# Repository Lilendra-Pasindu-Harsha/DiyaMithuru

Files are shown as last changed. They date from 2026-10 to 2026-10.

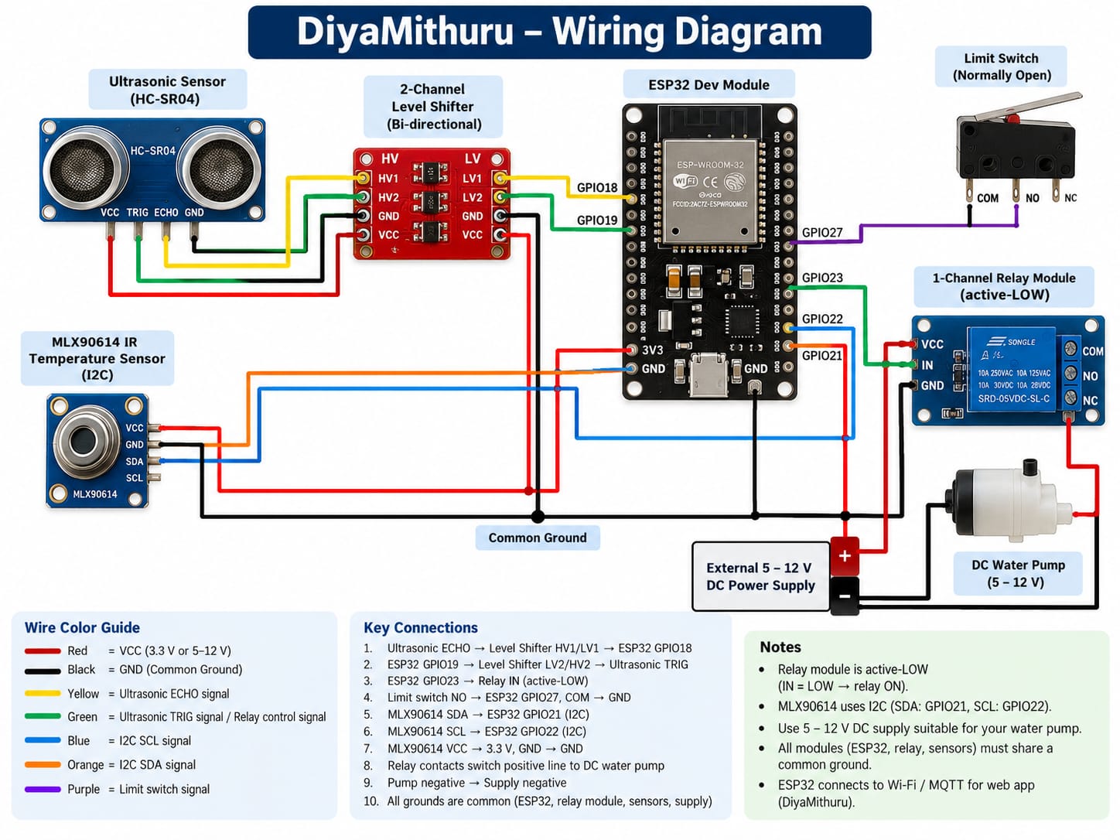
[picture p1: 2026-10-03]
firmware/Wiring Diagram.jpg

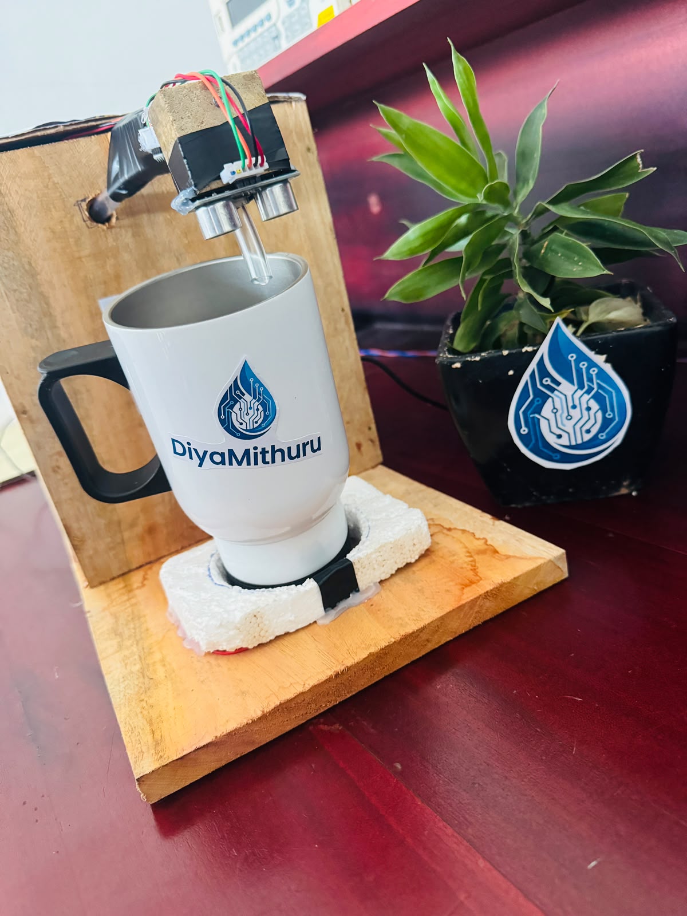
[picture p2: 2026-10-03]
Images/ProtoType/Front View 2.jpg

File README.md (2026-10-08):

# 💧 DiyaMithuru – Smart Liquid Filling Assistant

> **Technology with Compassion. For a More Inclusive Tomorrow.**

DiyaMithuru is an **ESP32-based smart liquid filling assistant** developed as part of the **Engineering Product Design module at General Sir John Kotelawala Defence University , Sri Lanka**.

The system is designed primarily for **visually impaired users**, with the goal of making everyday liquid filling safer, easier, and more independent.

Developed by:

- **Pasindu**
- **Dinuth**

---
Do you want watch all click  https://drive.google.com/drive/folders/1cJ1TSZ0RsK_wuHSQsSrhiei4Du43ArKO?usp=drive_link 

## 🌟 Project Overview

For many people, filling a cup is a simple daily activity. However, visually impaired users, elderly users, and people who require daily assistance may face challenges such as:

- Difficulty identifying the liquid level
- Accidental spills
- Unnecessary water wastage
- Safety concerns when handling higher-temperature liquids
- Dependence on another person

DiyaMithuru addresses these challenges through an embedded automatic filling system with liquid-level monitoring, temperature sensing, remote status monitoring, and user control.

---

## ✨ Key Features

- Automatic cup detection
- Automatic liquid filling
- Automatic refill when the liquid level becomes low
- Pump stops when the cup reaches the full threshold
- Pump stops immediately when the cup is removed
- Liquid-level monitoring using an ultrasonic sensor
- Temperature monitoring using the **MLX90614 IR temperature sensor**
- Manual **ON / STOP / FILL / TEMP** commands
- Wi-Fi setup using **WiFiManager**
- MQTT communication using **HiveMQ Cloud**
- Live device status on the web application
- Spoken announcements through the user interface
- Pump safety timeout
- Sensor fault handling
- Wi-Fi credential reset function

---

## ⚙️ How the System Works

```text
Place Cup
   ↓
Limit Switch Detects Cup
   ↓
Ultrasonic Sensor Measures Liquid Level
   ↓
ESP32 Processes Sensor Data
   ↓
Pump Starts
   ↓
Cup Fills
   ↓
Full Threshold Reached
   ↓
Pump Stops
   ↓
Wait 2 Seconds
   ↓
MLX90614 Measures Drink Temperature
   ↓
Status Published Through MQTT

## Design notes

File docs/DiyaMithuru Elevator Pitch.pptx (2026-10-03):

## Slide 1

DiyaMithuru prototype

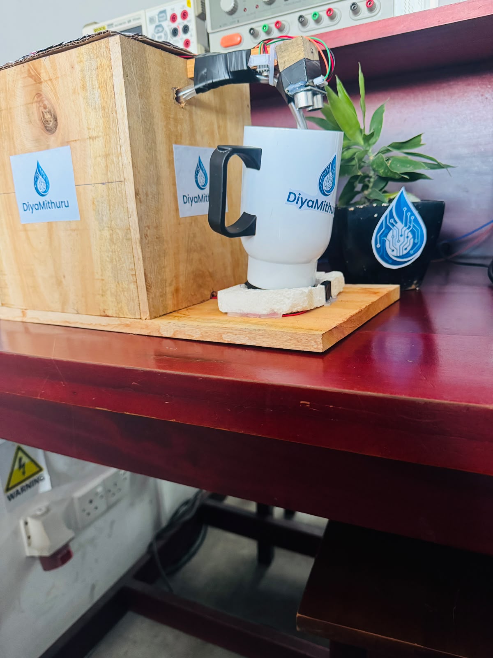
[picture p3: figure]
WhatsApp Image 2026-09-30 at 15.35.14

DiyaMithuru

Smart Liquid Filling Assistant

Technology with Compassion

“A safer, easier and more independent way to fill your cup.”
D/ENG/24/0095/ET
M/ENG/24/001/ET

Designed & Developed in Sri Lanka

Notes: Good evening all .Today we are here to present our newly product DiyaMithuru.It is Smart Liquid Filling Assistant.It helps people fill a cup safely and independently.

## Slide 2

A Simple Task Can Be Difficult

“Filling a cup is not easy for everyone.”

Difficulty identifying liquid level

Risk of spills

WHO IS AFFECTED

Visually Impaired Individuals

Elderly People

People needing daily assistance

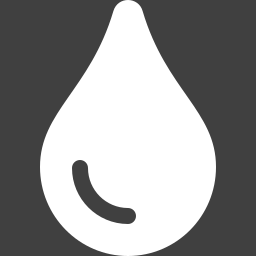
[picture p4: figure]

Safety concerns

Dependence on others

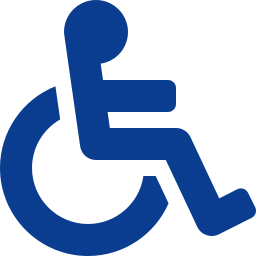
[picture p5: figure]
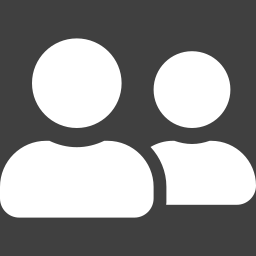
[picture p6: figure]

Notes: Many people find it difficult to fill a cup. Visually impaired and elderly people may spill hot liquids or need help from others.

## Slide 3

Meet DiyaMithuru

Smart Assistance for Everyday Liquid Filling

WhatsApp Image 2026-09-30 at 15.35.13

Automatic Filling

Temperature Monitoring

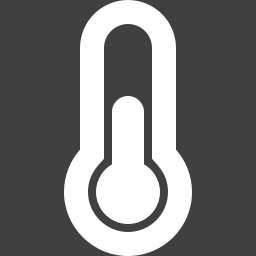
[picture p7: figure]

Audio Indication

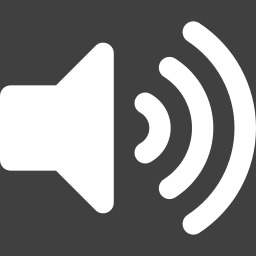
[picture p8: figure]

Inclusive Design

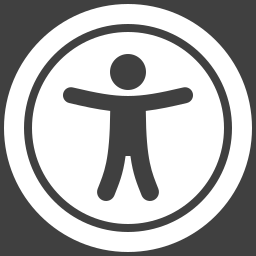
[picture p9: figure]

“Designed to make everyday liquid filling safer, simpler and more independent.”

PLACE

→

DETECT

→

FILL

→

INDICATE

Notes: DiyaMithuru detects the cup, fills it automatically, checks the temperature, and gives an audio indication. It makes filling safer and easier.

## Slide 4

Designed for Real Daily Needs

PRIMARY USER

Visually Impaired Individuals

SECONDARY USERS

Elderly People

Children & Caregivers

Recovery / Patient Support

General Home Users

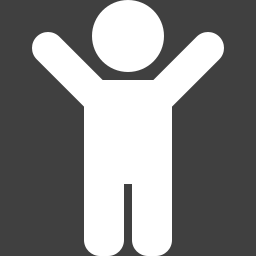
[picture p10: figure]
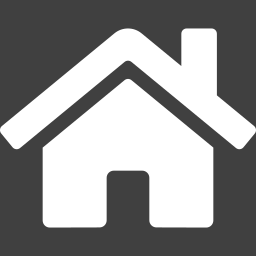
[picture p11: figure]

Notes: It is mainly designed for visually impaired people. It can also help elderly people, caregivers, patients, and families.

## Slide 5

How DiyaMithuru Works

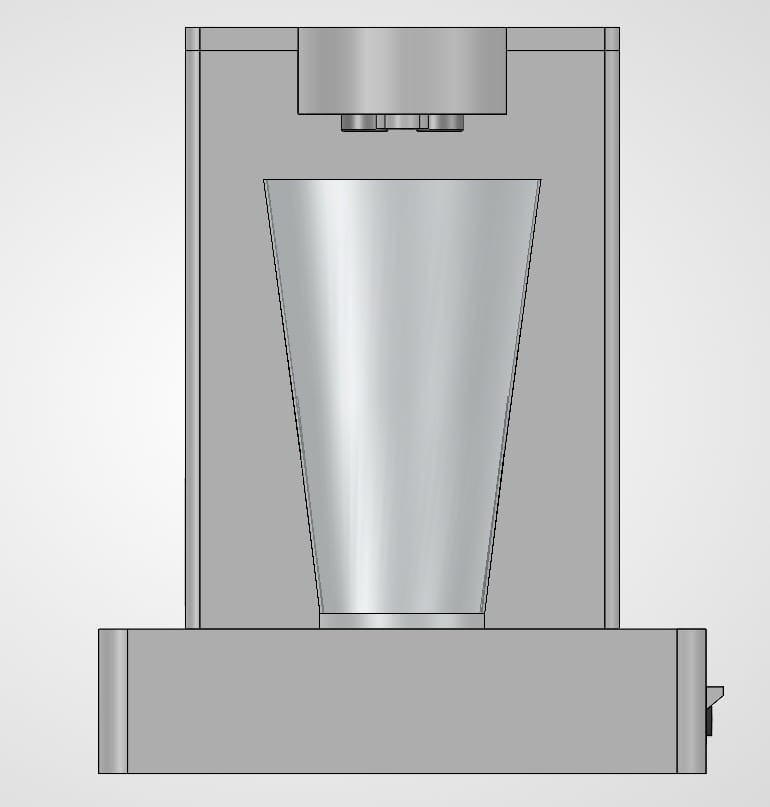
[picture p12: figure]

ESP32 Controller

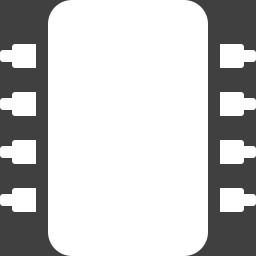
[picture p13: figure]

Ultrasonic Sensor

Temperature Sensor

Relay Module

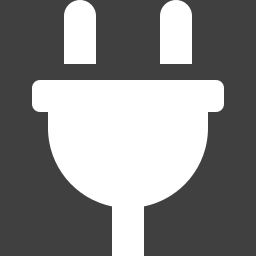
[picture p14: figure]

DC Water Pump

12 V Power Supply

1

Place the cup

›

2

Cup is detected

›

3

ESP32 processes the input

›

4

Pump dispenses the liquid

›

5

Temperature is monitored

›

6

Audio indication informs the user

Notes: The user places a cup. The system detects it, fills the liquid, monitors the temperature, and gives an audio notification when finished.

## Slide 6

More Than Just a Product

GREATER INDEPENDENCE

IMPROVED SAFETY

MORE CONFIDENCE

EASIER DAILY LIVING

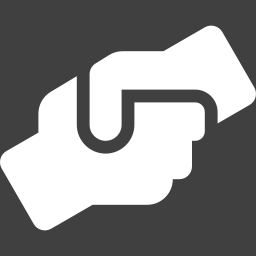
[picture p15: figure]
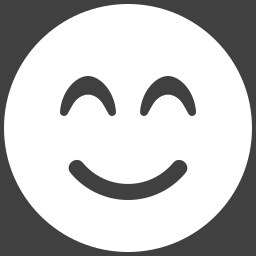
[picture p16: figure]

Supporting Inclusive Technology in Sri Lanka

Technology with Compassion.

Visually impaired user

Elderly user

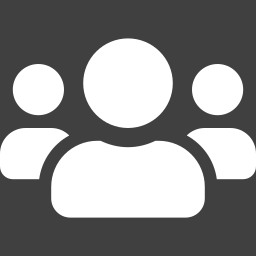
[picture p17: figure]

Family / caregiver

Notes: IMPACT - 20s. Independence, safety, confidence, easier daily living. Close on Technology with Compassion.

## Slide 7

From User Need to Real Product

User Feedback

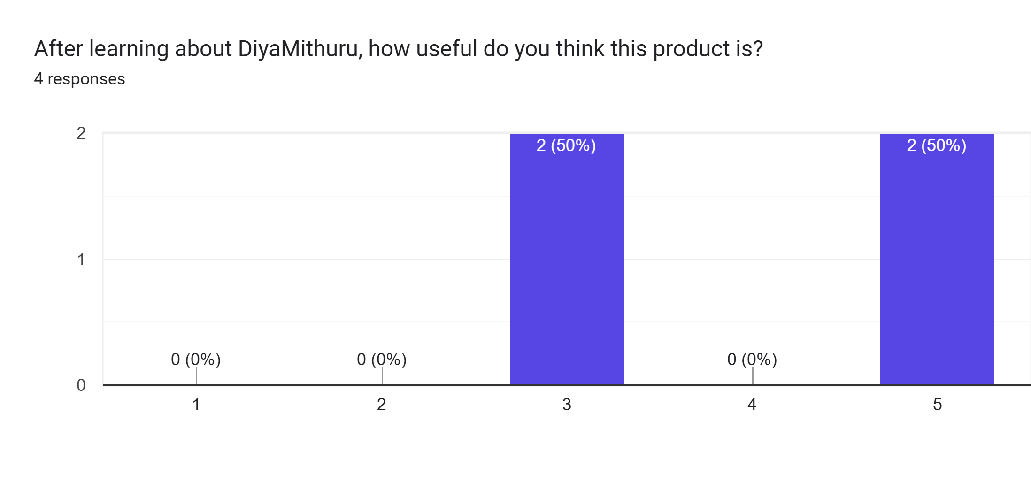
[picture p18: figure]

[INSERT REAL CUSTOMER FEEDBACK]

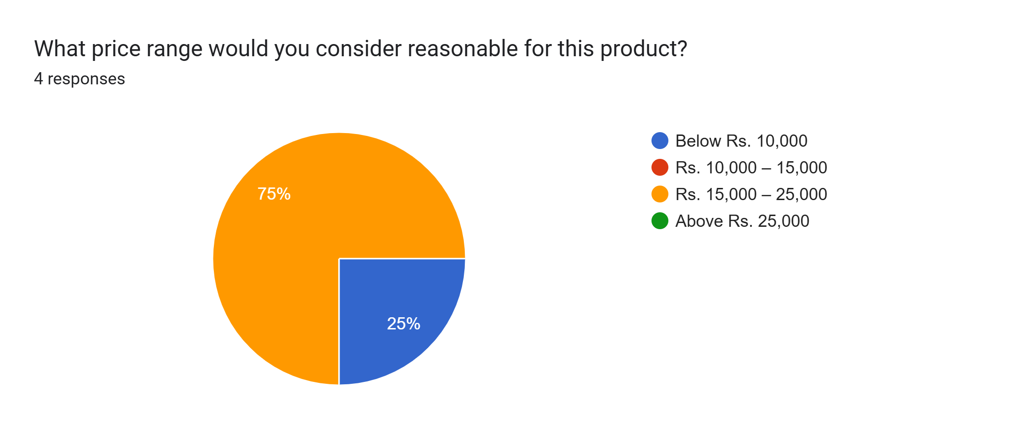
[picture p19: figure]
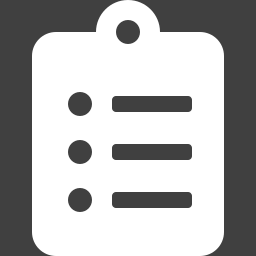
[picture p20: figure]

Google Form Survey

Prototype Testing

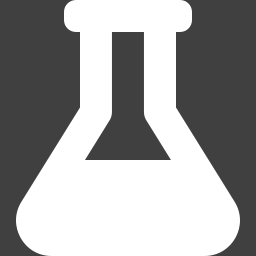
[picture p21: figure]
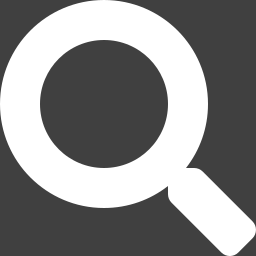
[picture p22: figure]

Customer Requirement Analysis

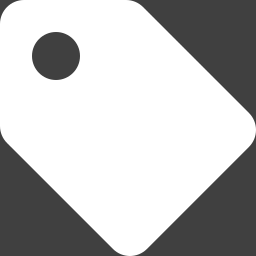
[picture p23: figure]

Price Validation

PRODUCT-MARKET FIT

LOCALLY DEVELOPED

AFFORDABLE

USER-CENTERED

INCLUSIVE

SIMPLE TO USE

Link - https://docs.google.com/forms/d/1FdYKrwL7_DrpVTMPInImFrXas6RZh5WQtF1M-O45piI/edit (https://docs.google.com/forms/d/1FdYKrwL7_DrpVTMPInImFrXas6RZh5WQtF1M-O45piI/edit)

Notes: We collected user feedback, tested the prototype, and analyzed customer needs. The results show that DiyaMithuru is useful and affordable.

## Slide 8

Affordable Assistive Technology

STANDARD PRICE

~~LKR 15,000~~

PROMOTIONAL OFFER: 5% DISCOUNT

PROMOTIONAL PRICE

LKR 14,250

INSTALLMENT PLAN

LKR 5,000 / month

for 3 months · 0% Interest

SCAN

1-Year Hardware Warranty

Free Islandwide Delivery

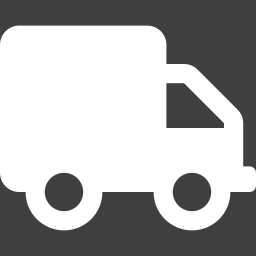
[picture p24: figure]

Personal Onboarding

Wall Power Adapter & Accessories

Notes: The price is LKR 15,000, with a promotional price of LKR 14,250. We also offer installments, a warranty, and free delivery.

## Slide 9

FUTURE DEVELOPMENT

Smart Connectivity
Using AI

IoT Integration using Camera

Improved Audio Guidance
in Tri Basha

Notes: FUTURE - 5s. Roadmap only. Future development items are not current features.

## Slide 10

Thank You !

Technology with Compassion

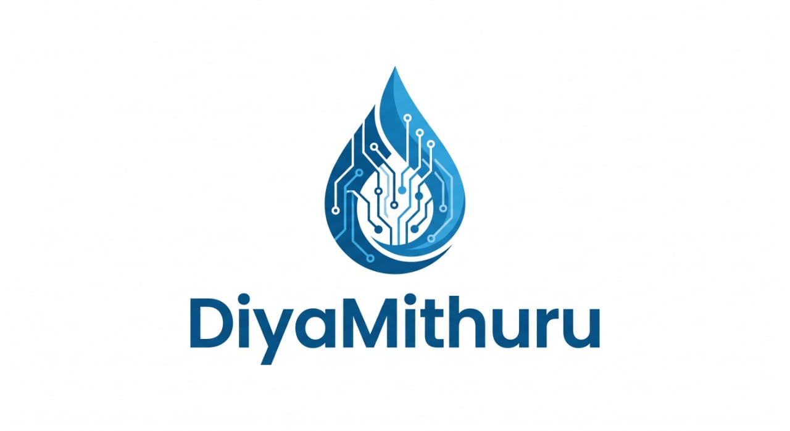
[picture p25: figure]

Scan to know more

“For a More Inclusive Tomorrow”

Designed & Developed in Sri Lanka

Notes: Thank you for listening. DiyaMithuru is Technology with Compassion, created for a more inclusive tomorrow.

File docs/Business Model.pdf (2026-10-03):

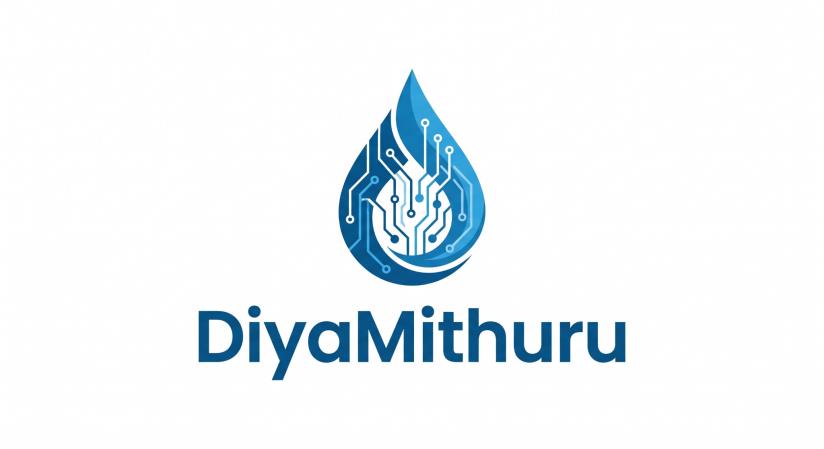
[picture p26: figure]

# BUSINESS MODEL, PRODUCT COST

# & SWOT ANALYSIS


## SMART LIQUID FILLING ASSISTANT

DiyaMithuru is an inclusive smart liquid filling assistant designed to make routine liquid dispensing safer and easier. The primary design focus is visually impaired users, while the commercial concept also considers older adults, caregivers, children/baby-care routines, and people who need support with regular hydration.

The proposed business approach is a direct-to-customer model supported by institutional partnerships, a simple web-based pre-order channel, an upfront payment option, and a 0% three-month installment plan. The standard selling price is LKR 15,000, with a limited promotional cash price of LKR 14,250.

### 1. BUSINESS MODEL

The business model converts the engineering prototype into a practical customer offering. It focuses on affordability, accessibility, local support, and a clear route from prototype validation to small-batch sales.

Customer Segments Primary: visually impaired individuals. Secondary: older adults, caregivers, families, rehabilitation users and people who need assisted hydration. Institutional: hospitals, elder-care facilities, rehabilitation centres, NGOs and accessibility programmes. | Value Proposition A simple smart filling assistant that reduces manual pouring, supports safer liquid handling, improves independence and provides an accessible home-use experience at a locally targeted price.
Channels Direct website/pre-order page, social media promotion, university exhibitions, demonstrations, healthcare/rehabilitation partnerships, NGOs and direct institutional sales. | Customer Relationships Product demonstration, personal onboarding, one-year hardware warranty, user guidance, after-sales support and feedback collection for future product improvement.
Revenue Streams Standard outright sale: LKR 15,000. Promotional full-payment price: LKR 14,250 (5% discount). 0% installment plan: LKR 5,000 per month for 3 months. Future revenue may include institutional/bulk sales and upgraded product versions. | Key Activities Prototype refinement, assembly, quality checking, user testing, supplier sourcing, marketing, order fulfilment, customer onboarding, warranty support and continuous design improvement.
Key Resources ESP32-based control system, sensors and pump assembly, product enclosure, design files, website/pre-order channel, engineering know-how, user feedback and supplier network. | Key Partners Electronics suppliers, fabrication/enclosure providers, healthcare/rehabilitation organisations, disability-support organisations, delivery partners and academic/technical mentors.
Cost Structure Electronic components, enclosure/fabrication, pump and tubing, power adapter, assembly/testing labour, packaging, delivery, warranty reserve, marketing and website/administration costs. | Growth Path Start with small-batch direct sales, validate reliability and user satisfaction, build institutional partnerships, improve manufacturability, then expand to wider assistive/home-care markets.

Business model statement: DiyaMithuru will initially follow a direct-to-customer, small-batch model to keep the product affordable and maintain close contact with users. Institutional partnerships can later support bulk deployment and broader market reach.

1.1 Proposed Sales and Payment Model

Option | Customer Payment | Total Revenue | Purpose
Standard full payment | LKR 15,000 once | LKR 15,000 | Normal retail sale
Promotional full payment | LKR 14,250 once | LKR 14,250 | 5% launch promotion
0% installment plan | LKR 5,000 x 3 months | LKR 15,000 | Improves affordability / access

### 2. PRODUCT COST AND PRICING

The following cost model is an estimated planning budget for one DiyaMithuru unit. It is intended for the assignment business case and should be updated using actual purchase receipts, supplier quotations and fabrication costs before the final presentation.

Item | Qty | Estimated Unit Cost
(LKR) | Estimated Total (LKR)
ESP32 controller | 1 | 1,600 | 1,600
Ultrasonic cup-detection sensor | 1 | 450 | 450
Temperature sensor | 1 | 500 | 500
1-channel relay module | 1 | 250 | 250
Logic-level shifter | 1 | 300 | 300
DC liquid pump | 1 | 1,200 | 1,200

Wall power adapter /
power unit | 1 | 1,000 | 1,000

Tubing and fluid
connectors
1 | 400 | 400

Product enclosure /
fabricated body | 1 | 1,700 | 1,700

Wiring,
PCB/prototyping board,
fasteners
1 | 600 | 600

Audio indication
hardware | 1 | 450 | 450

Packaging, user guide
and warranty materials | 1 | 350 | 350

Assembly and functional
testing allowance | 1 | 700 | 700

Estimated
manufacturing cost per
unit

LKR 9,500

2.1 Pricing and Margin

Scenario | Selling Price | Gross Profit / Unit | Gross Margin
Standard retail | LKR 15,000 | LKR 5,500 | 36.7%
5% promotional full payment | LKR 14,250 | LKR 4,750 | 33.3%

Installment (3 x LKR
5,000) | LKR 15,000 | LKR 5,500 | 36.7%

Gross margin is before delivery, warranty claims, marketing, payment collection costs, taxes/fees and other overheads. These should be tracked separately during commercialization.

2.2 Small-Batch Financial Projection

Scenario | 20-Unit Revenue | 20-Unit Product
| | Cost | Gross Contribution
Standard price | LKR 300,000 | LKR 190,000 | LKR 110,000

All units at promo
price | LKR 285,000 | LKR 190,000 | LKR 95,000

Illustrative mixed
sales (10 standard +

### 10 promo)

LKR 292,500 | LKR 190,000 | LKR 102,500

2.3 Financial Plan for the First Product

- Use the website/pre-order QR code and product demonstration to collect the first confirmed order.
- Offer the standard price of LKR 15,000, or a limited 5% promotional full-payment price of LKR 14,250.
- Offer the 0% installment option at LKR 5,000 per month for three months while keeping the total price at LKR 15,000.
- Purchase components against confirmed orders where possible to reduce inventory risk and preserve working capital.
- Record actual component, fabrication, delivery and warranty costs for each unit so the final selling price can be refined using real data.

Estimated first-unit economics at promotional price: Revenue LKR 14,250 - estimated product cost LKR 9,500 = estimated gross contribution LKR 4,750 before delivery, warranty and marketing overheads.

### 3. SWOT ANALYSIS

The SWOT analysis identifies internal product/business factors and external market factors that can affect DiyaMithuru during prototype validation and early commercialization.

STRENGTHS

- Inclusive, user-centered concept with a clear
primary accessibility need.
- Locally developed solution that can be supported and adapted for Sri Lankan users.
- Simple embedded architecture based on commonly available components.
- Automatic cup detection, liquid dispensing, temperature monitoring and audio indication improve ease of use.
- Potential to serve more than one customer segment while retaining a strong accessibility focus.
- Web-based marketing/pre-order channel enables low-cost direct customer reach.

WEAKNESSES

- Alpha-stage product with limited long-term reliability and field testing.
- Current unit cost may be high relative to mass-produced household dispensers.
- Performance depends on correct sensor positioning, calibration and consistent cup placement.
- Small-batch fabrication can cause variation in enclosure quality and assembly time.
- Warranty, delivery and installment commitments can create extra cost and cash-flow pressure.
- Product is not a medical measuring device; claims about patient fluid requirements must remain carefully limited.

OPPORTUNITIES

- Growing interest in inclusive design, independent living and smart-home assistance.
- Partnership opportunities with hospitals, rehabilitation centres, elder-care services and NGOs.
- Potential institutional/bulk orders after successful user validation.
- Future versions can improve portability, manufacturability, connectivity and personalised accessibility features.
- Local manufacturing and assembly may reduce import dependence and improve after-sales support.
- Positive university exhibition and survey feedback can support further product development.

THREATS

- Competition from low-cost water dispensers, smart appliances and imported assistive products.
- Component price changes or shortages can reduce margins.
- Electrical/liquid safety concerns may require stronger testing and compliance before commercial release.
- Customer adoption may be slow without demonstrations and trust-building.
- Sensor or pump failure can directly affect customer confidence in the product.
- Unvalidated marketing claims could create reputational or regulatory risk.

3.1 Actions from the SWOT

Priority | Action

Validate reliability

Run repeat filling tests, temperature-sensor checks and user trials; document failures and improvements.

Control product cost

Use | supplier | quotations, | standardise
components and redesign the enclosure for easier small-batch manufacturing.

Build customer trust

Demonstrate the product, clearly explain limitations, provide onboarding and publish genuine user feedback.

Manage commercial risk

Define warranty terms, installment collection rules, delivery cost policy and a small warranty reserve per unit.

### 4. CONCLUSION

DiyaMithuru has a credible early-stage business pathway because the product addresses an identifiable accessibility need, uses a comparatively simple embedded architecture and can initially be sold through direct customer relationships. The proposed LKR 15,000 standard price and LKR 14,250 promotional price provide a workable starting point under the estimated LKR 9,500 unit-cost model, but the financial case must be updated with real supplier and fabrication data before commercial launch.

The immediate business priority is not large-scale expansion. It is to validate reliability, confirm customer willingness to pay, control unit cost and build trust through real demonstrations and user feedback. These results can then support institutional partnerships and future product development.

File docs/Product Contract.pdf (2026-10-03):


# PRODUCT CONTRACT


# SMART LIQUID FILLING ASSISTANT

Product | DiyaMithuru
Category | Assistive Technology
Prototype | Alpha
Design focus | Inclusive, user-centered operation

### 1. PRODUCT DESCRIPTION

DiyaMithuru is an inclusive smart liquid filling assistant designed to reduce the need for visual judgement and manual pouring. The alpha prototype uses an ESP32-based control system, ultrasonic sensing for cup presence, temperature sensing, relay-controlled pumping and audio

indication using web dashboard. When a cup is correctly positioned, the system can initiate controlled dispensing, monitor the liquid condition, provide visual and non-visual feedback using web site , and stop the pump according to the programmed filling condition. ALPHA SCOPE
Prototype validation is based primarily on water and indoor home-use conditions. It is not a certified medical dosing device and should not be presented

### as one. 2. VALUE PROPOSITION

Who is the user?

Primary: people with full visual impairment who need a non-visual way to fill a cup. Secondary users include older adults, people with reduced dexterity, caregivers, and people recovering from illness who

benefit from easier hydration routines. How does the user benefit?

Less dependence on sight and continuous manual pouring; easier cup placement and filling; audio status feedback; temperature awareness and reduced risk of accidental dispensing when a cup is not correctly positioned. Where and when is it used?

Primarily indoors at home, including kitchens, dining spaces, bedside areas and assisted-living

environments. It can support routine drinking-water and beverage preparation. Why would someone want it?

It combines simple automation and inclusive interaction in one affordable local product, helping turn a common daily task into a more predictable and independent experience.

### 3. PRIMARY USER PERSONA

Persona | Nadeesha - hypothetical primary user
Profile | 32-year-old adult with full visual impairment who wants to prepare drinking water independently at home. Current challenge
| Cannot visually judge cup position or liquid level and may need assistance to avoid spills or unsafe handling. Goals
| Independent operation, minimal controls, clear audio feedback, predictable filling, simple cleaning, and safe use around the home. Critical needs
| Non-visual operation; cup-presence interlock; automatic pump control; temperature awareness;

audible start/complete/warning feedback. 4. TARGET MARKET

Primary market: Individuals and households where a visually impaired person wants greater independence in daily liquid filling. Secondary market: Older adults, people with reduced hand dexterity or mobility, caregivers, and

families supporting children or people in recovery. Institutional market: Rehabilitation centers, elder-care settings, disability-support organizations, selected healthcare environments, NGOs and inclusive-living programs. Positioning: Affordable, locally developed assistive technology focused on simple operation, accessibility, and everyday practicality.

### 5. USER NEEDS, PRODUCT ATTRIBUTES & ENGINEERING SPECIFICATIONS

The following requirements convert user needs into measurable design targets. Numeric values are acceptance targets for the alpha prototype and should be confirmed by testing before final
submission. User Need | Product Attribute | Required Function
Engineering
Specification /
Acceptance Target

Verification

Independent, non- visual use Cup detection

System shall identify a
correctly positioned cup
before enabling liquid
dispensing. | Target: >=95% successful detection in 20 placement
trials. | Repeated placement
test

No accidental
dispensing
Safety interlock | Pump shall remain OFF
when no cup is detected. | Target: 20/20 no-cup trials
with zero unintended
pump activation. | No-cup safety test

Quick operation Control response

System should respond
promptly after valid cup
detection. | Target: pump control response <=1.0 s after
stable valid detection. | Stopwatch

Consistent filling

Automatic
dispensing
Liquid | shall | be
dispensed | using | a
programmed | filling
condition rather than
continuous | manual
control. | Target: | repeated | fill
quantity within +/-10%
under the same cup, pump

and supply conditions. 10-fill volume test

Automatic
completion

Pump control

Pump shall turn OFF
automatically at the
programmed fill
condition and include a
maximum | run-time
safeguard. | Target: automatic stop every cycle; maximum continuous pump ON time
<=60 s. | Cycle test

Temperature
awareness

Temperature
monitoring

System shall measure
liquid temperature over
the normal beverage
range. | Design target: 0-100 degC measurement range; +/-2 degC accuracy from 20-80
degC. | Compare | with
| reference thermometer

User Need | Product Attribute | Required Function

Engineering
Specification /
Acceptance Target

Verification

Clear non-visual
feedback | Audio indication
Provide | audible
indication for key states
such as ready/start, completion | and
warning. | Target: distinct audible cues; minimum 65 dBA at 0.5 m in a quiet indoor
setting. | Sound-level / user recognition test
Simple interaction | User interface

Normal operation shall
not | require | a
touchscreen or visual
menu. | Target: <=1 intentional user action after placing the cup; audio feedback
available. | Task analysis / user trial

Low-voltage home
use

Power & electrical
safety

Use a low-voltage DC
supply for the prototype
electronics and pump
system. | 5-12 V DC system supply; wall adapter used as
external mains interface. Visual inspection / voltage check

Reliable operation System reliability

System shall complete
repeated fill cycles
without controller lock- up or pump-control
failure. | Target: >=100 consecutive
bench cycles without
control failure. | Endurance test
Indoor | liquid
handling

Operating scope

Alpha prototype shall be
validated with water and
similar low-viscosity
test liquids only after
compatibility check. | Minimum | validation
| medium: | water;
electronics protected from
normal splash exposure by
enclosure/layout. | Inspection / functional test

Affordable
ownership

Cost target

Product should remain
accessible relative to
complex | imported
assistive systems. | Planning | target:
| manufacturing | cost
<=LKR 9,500; standard
selling price <=LKR
15,000. | BOM and cost review

### 6. ALPHA PROTOTYPE ACCEPTANCE CRITERIA

The alpha prototype will be considered successful when the core assistive function can be demonstrated safely and repeatedly under the defined test conditions. • Cup presence is detected reliably before dispensing begins. • The pump does not activate when a cup is absent or outside the valid placement zone. • Dispensing starts and stops automatically according to the programmed control logic. • Temperature sensing produces stable readings that are reasonably consistent with a reference

thermometer. • Audio indication communicates key system states without requiring visual feedback. • The device completes repeated demonstrations without leakage reaching exposed electronics

or causing control failure. • The primary user or a suitable representative can understand the operating sequence with

minimal instruction. • The final prototype enclosure and product form present a resolved, natural-product appearance

suitable for exhibition demonstration.

### 7. Verification Plan

Test | Method | Pass Evidence
Cup detection | 20 correct cup placements | Detection success rate and false negatives
No-cup interlock | 20 trials without a cup | Unintended pump activations = 0
Fill repeatability | 10 fills using same cup and setup | Measure each fill volume; calculate variation
Automatic stop | 10 full cycles | Pump stops without manual continuous control
Temperature | Compare at approximately 20, 40, 60 and 80 degC | Error against reference thermometer
Audio indication | Test ready/start/complete/warning cues | Cue is audible and distinguishable at 0.5 m
Endurance | 100 bench cycles | Record control failures, leaks or abnormal operation
User validation | Task trial with target-user representative | Observe independence, errors, ease of use and feedback

### 8.PRODUCT BOUNDARIES & ASSUMPTIONS

- The alpha prototype is intended for indoor demonstration and home-assistance scenarios. • The product is not positioned as a certified medical device, clinical fluid meter, or replacement

for professional medical advice. • For the final engineering report, measured prototype dimensions, weight, actual sensor

accuracy, measured fill repeatability, and endurance results should replace any unverified target values. • Web-based logging, mobile applications, AI recognition and smart-home connectivity are

outside the current alpha-prototype contract unless separately implemented and demonstrated. • Commercial claims such as warranty, delivery, manufacturing cost and retail price are

business-plan assumptions until a real production and service process is established.

Prepared by | Reviewed by | Date

### 9.CONTRACT SIGN-OFF


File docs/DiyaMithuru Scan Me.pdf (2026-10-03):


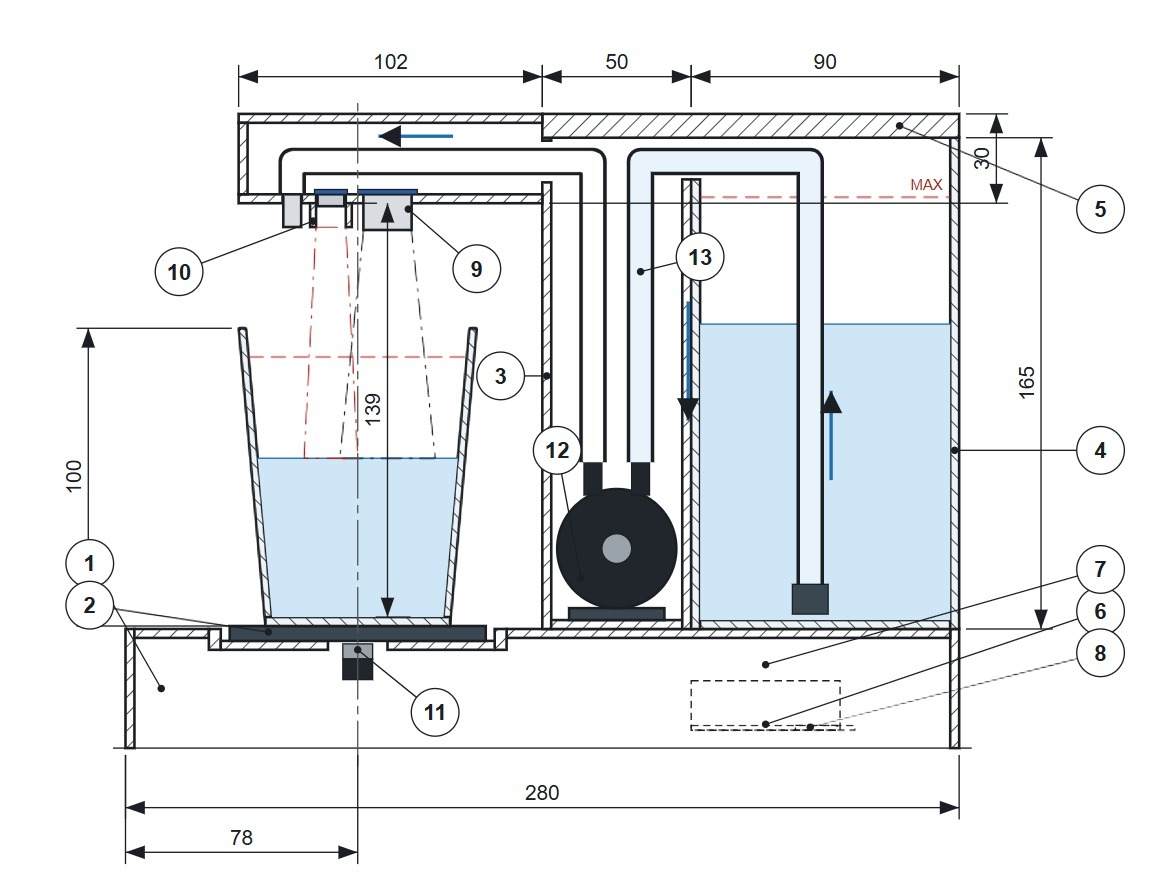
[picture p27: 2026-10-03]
Drawings/Mechanical/Side View with Dimensions.jpeg

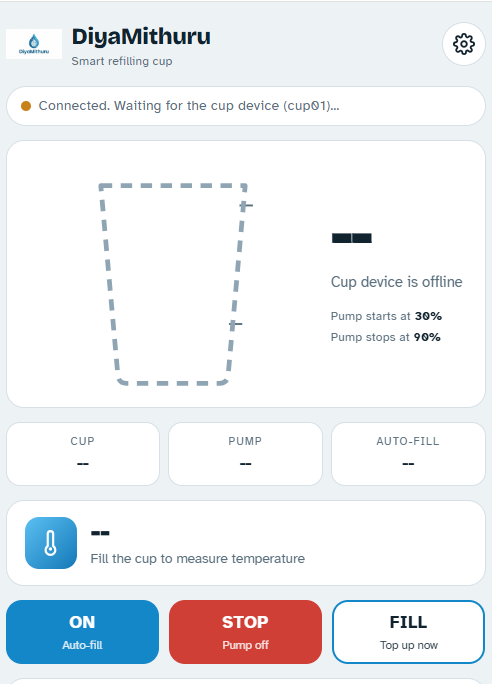
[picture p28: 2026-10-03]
Images/Working Unit Web Site/View 1.png

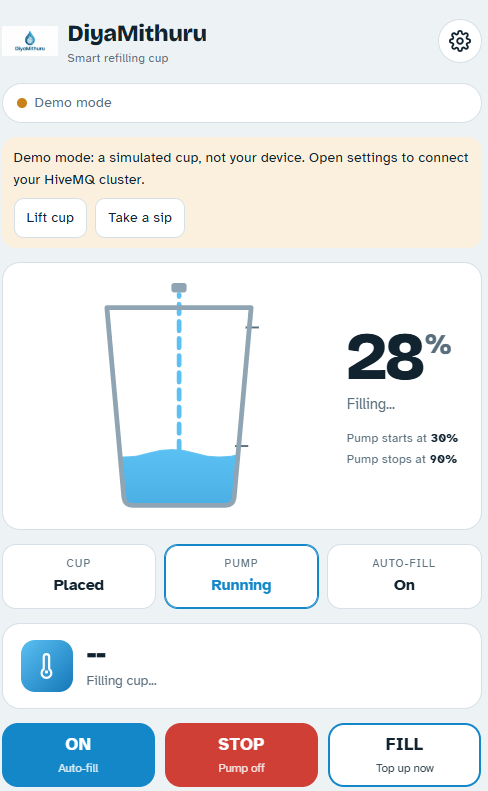
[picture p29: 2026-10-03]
Images/Working Unit Web Site/View 4.png

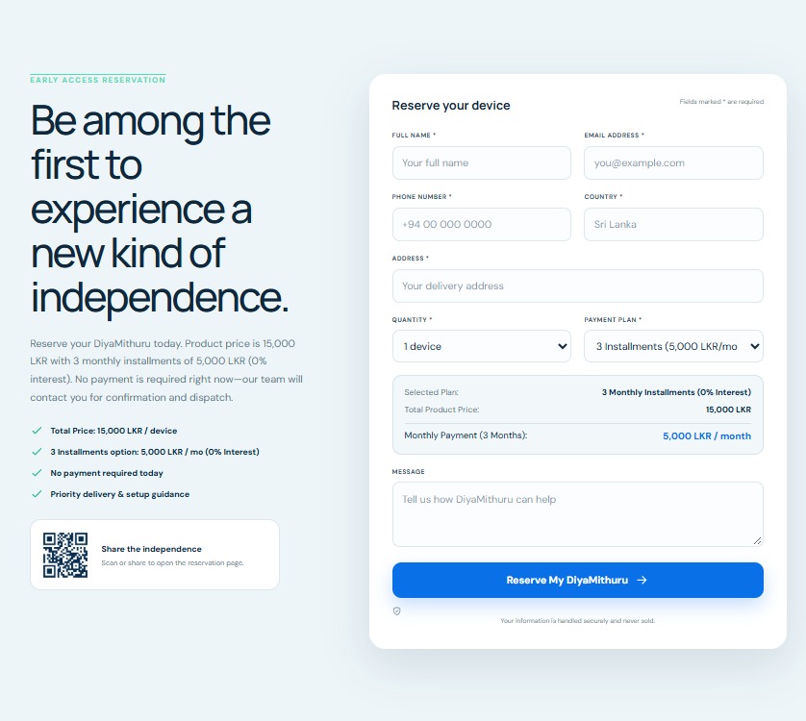
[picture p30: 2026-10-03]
Images/Marketing Web Site/View 8.jpg

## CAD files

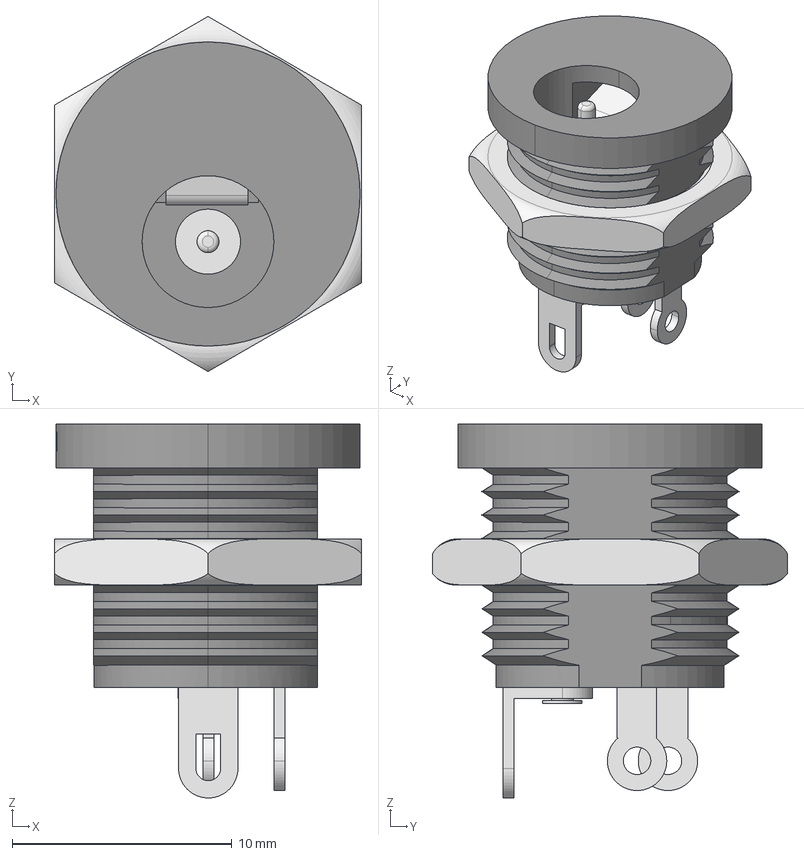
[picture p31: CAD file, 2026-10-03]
Drawings/CAD/Assem1/Socket Panel.stp
14.0 x 16.2 x 17.0 mm
Socket Panel
pin
Nut

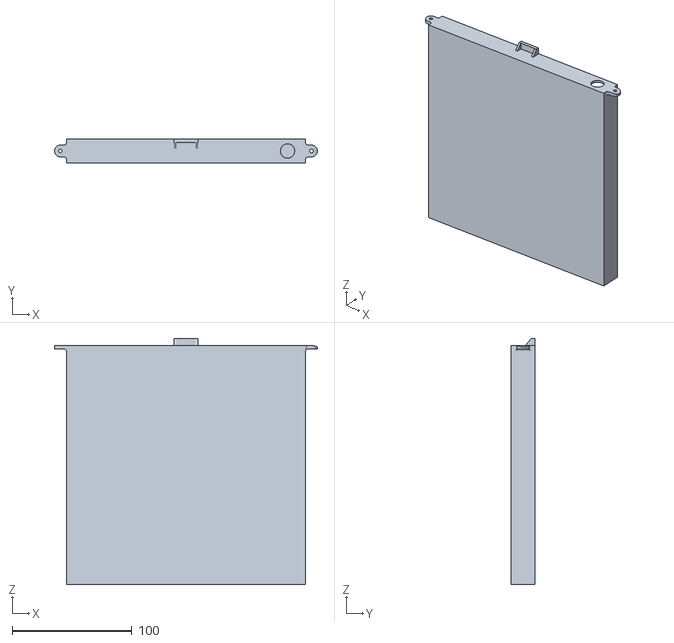
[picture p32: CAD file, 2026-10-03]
Drawings/CAD/pcb plate.STL
219.9 x 20.0 x 206.0

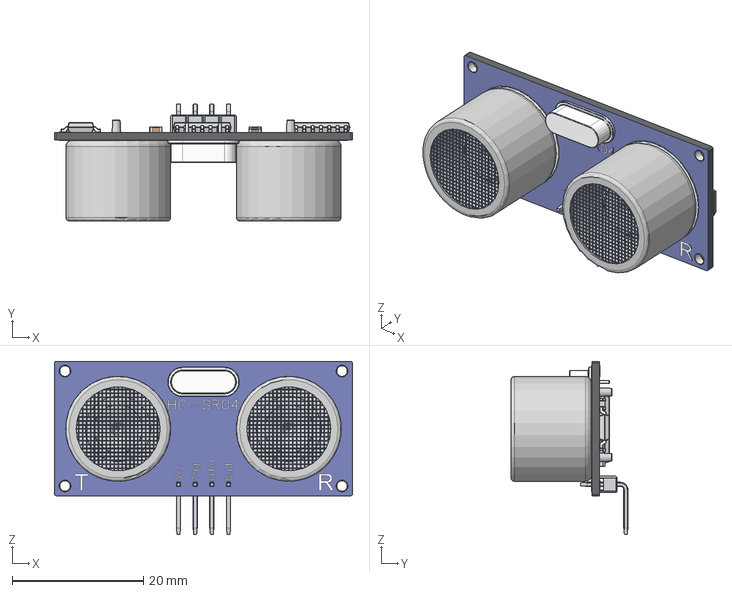
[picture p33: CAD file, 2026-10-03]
Drawings/CAD/Assem1/HC-SR04_UltraSonic Sensor.step
45.4 x 17.8 x 26.4 mm

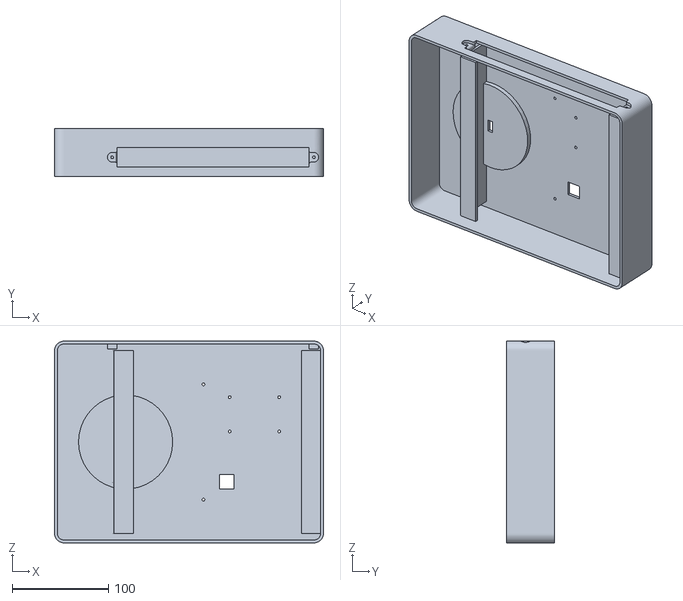
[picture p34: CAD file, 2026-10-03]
Drawings/CAD/base.STL
280.0 x 50.0 x 210.0

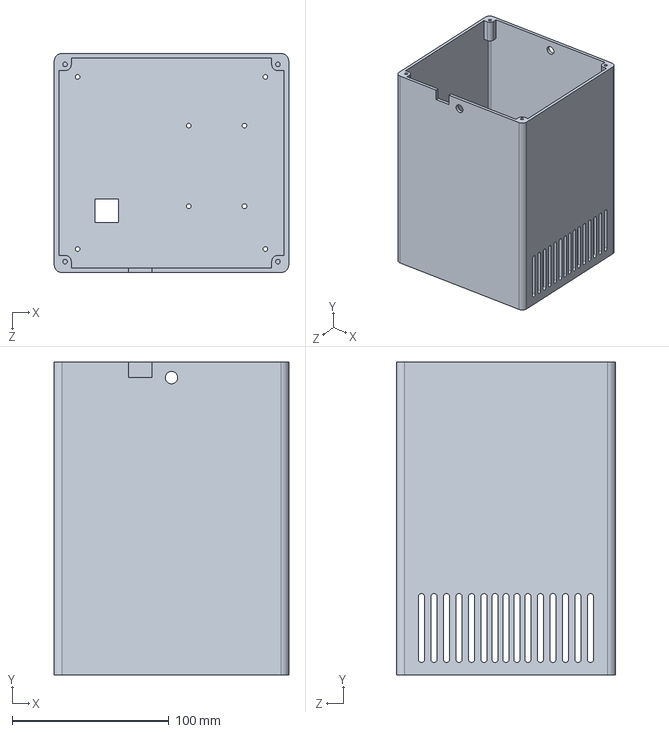
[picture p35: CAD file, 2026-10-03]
Drawings/CAD/Assem1/Drypump_bay.SLDPRT
150.0 x 200.0 x 140.0 mm

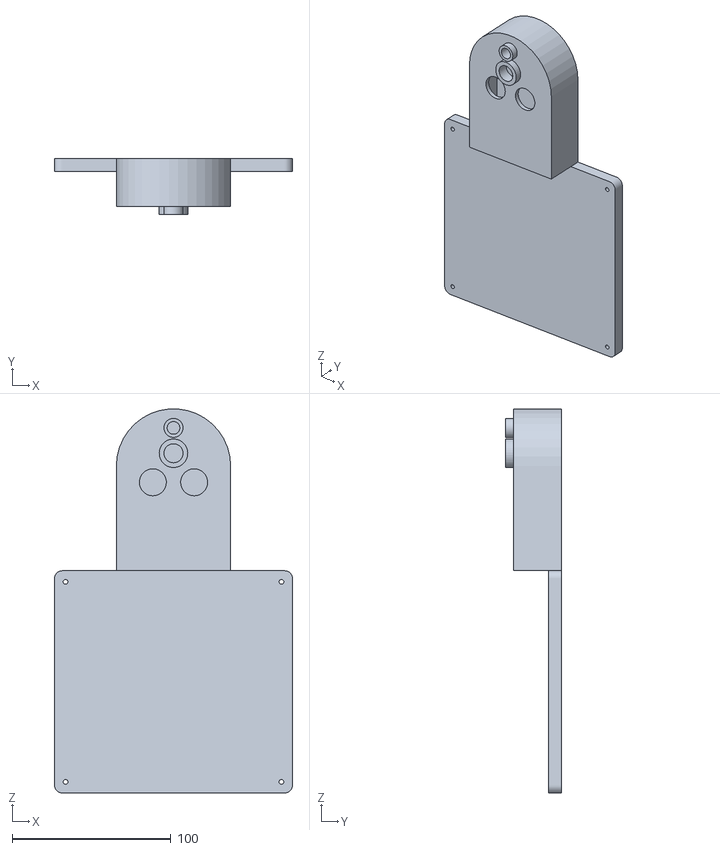
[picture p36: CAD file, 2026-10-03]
Drawings/CAD/Lid + sensor arm.STL
150.0 x 35.0 x 241.9

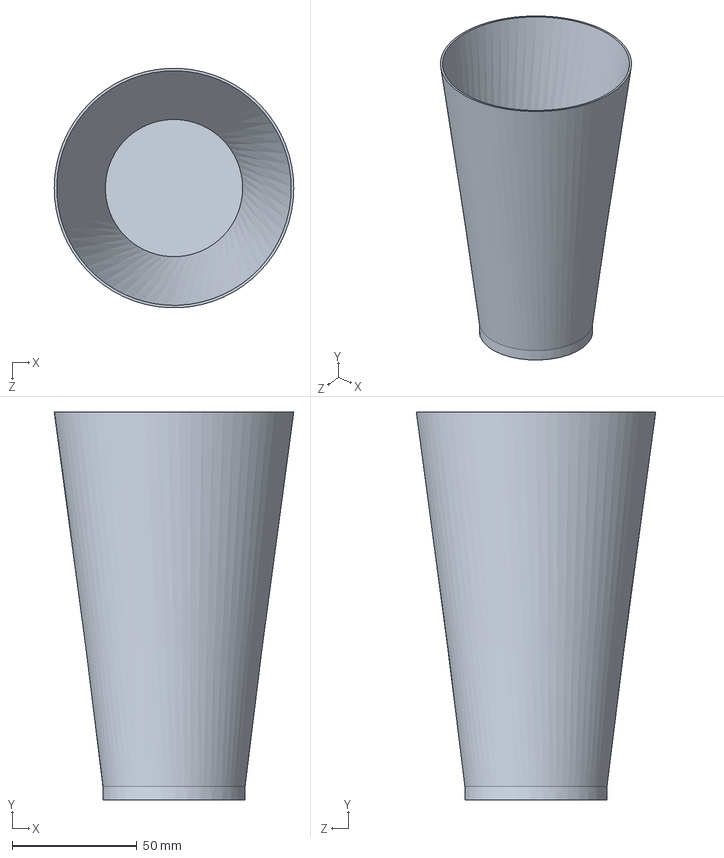
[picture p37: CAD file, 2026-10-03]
Drawings/CAD/Assem1/Water glass.SLDPRT
96.0 x 155.5 x 96.0 mm

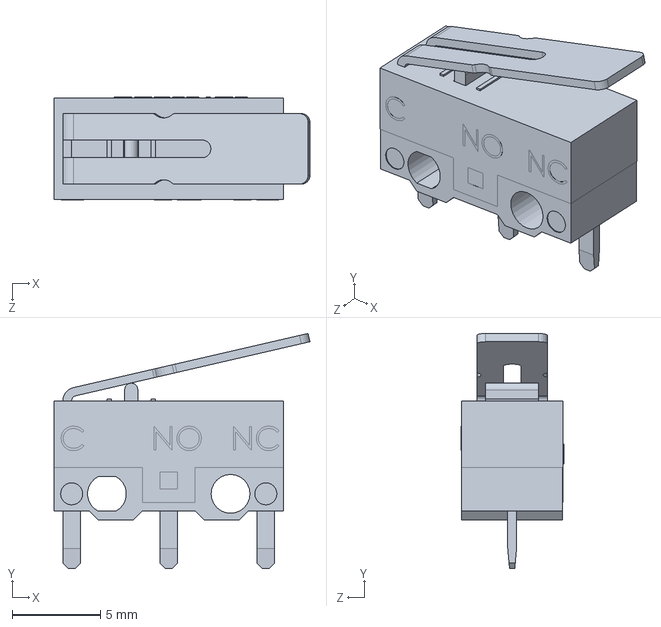
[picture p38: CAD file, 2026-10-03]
Drawings/CAD/Assem1/Limit_Switch.SLDPRT
14.5 x 13.3 x 5.81 mm

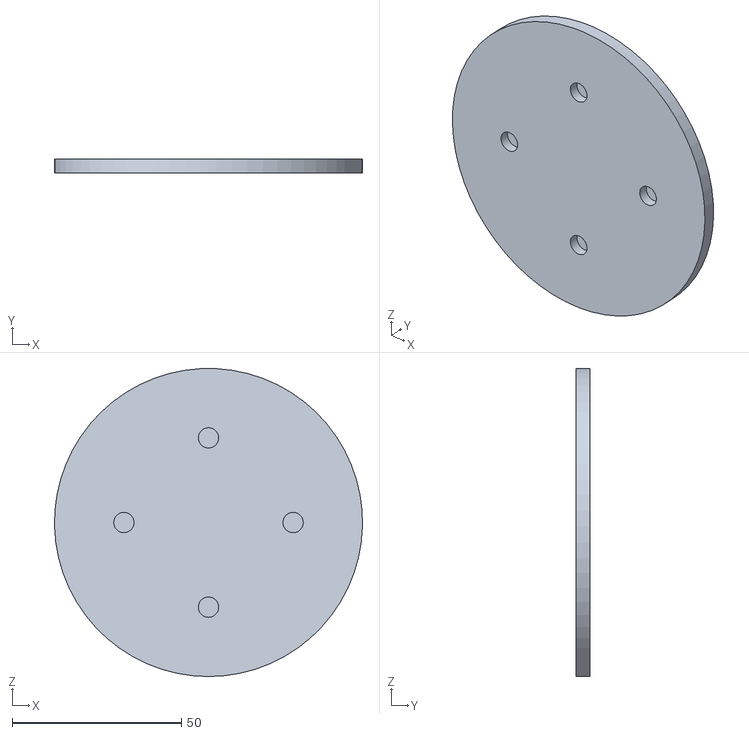
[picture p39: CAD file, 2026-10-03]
Drawings/CAD/Cup pad.STL
91.0 x 4.00 x 91.0

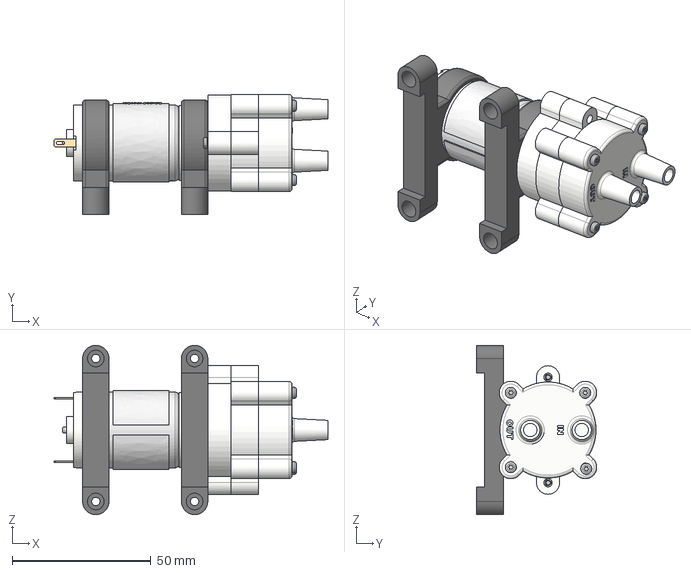
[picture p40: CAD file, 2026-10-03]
Drawings/CAD/Assem1/12V Diaphragm Pump RS-385 - WITH BRACKETS.iges
98.7 x 43.4 x 61.0 mm

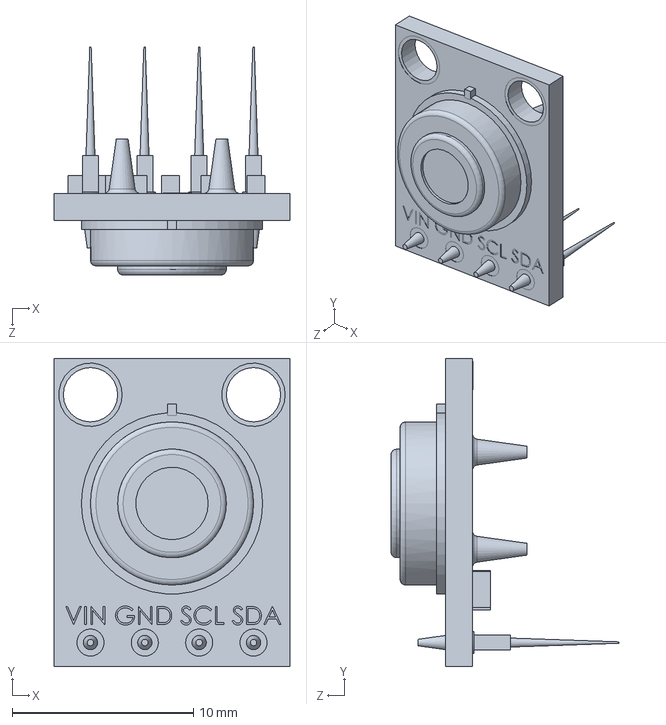
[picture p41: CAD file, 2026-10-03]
Drawings/CAD/Assem1/MLX 90614.SLDPRT
13.0 x 17.0 x 12.6 mm

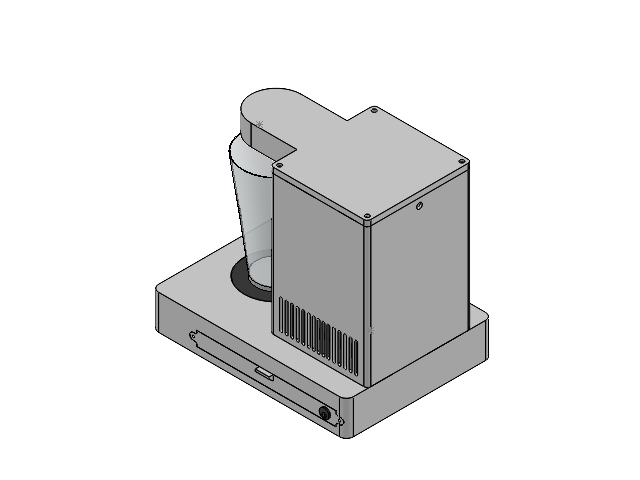
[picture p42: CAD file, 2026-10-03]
Drawings/CAD/Assem1/Assem1.SLDASM
base
Drypump_bay
Lid + sensor arm
HC-SR04_UltraSonic Sensor.step
Cup pad
Limit_Switch
Water glass
MLX 90614
Motor_Main_2.iges
Pump_Main_2.iges
99397A195_2.iges x 6
Rubber_Bracket.iges x 2
pcb plate
Socket Panel_1.stp
pin.stp
Nut.stp

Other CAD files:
Drawings/CAD/Drypump_bay.STL
Drawings/CAD/Assem1/Lid + sensor arm.SLDPRT
Drawings/CAD/Assem1/Cup pad.SLDPRT
Drawings/CAD/Assem1/pcb plate.SLDPRT
Drawings/CAD/Assem1/base.SLDPRT

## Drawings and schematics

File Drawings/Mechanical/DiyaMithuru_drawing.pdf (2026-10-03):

A

## TOP VIEW

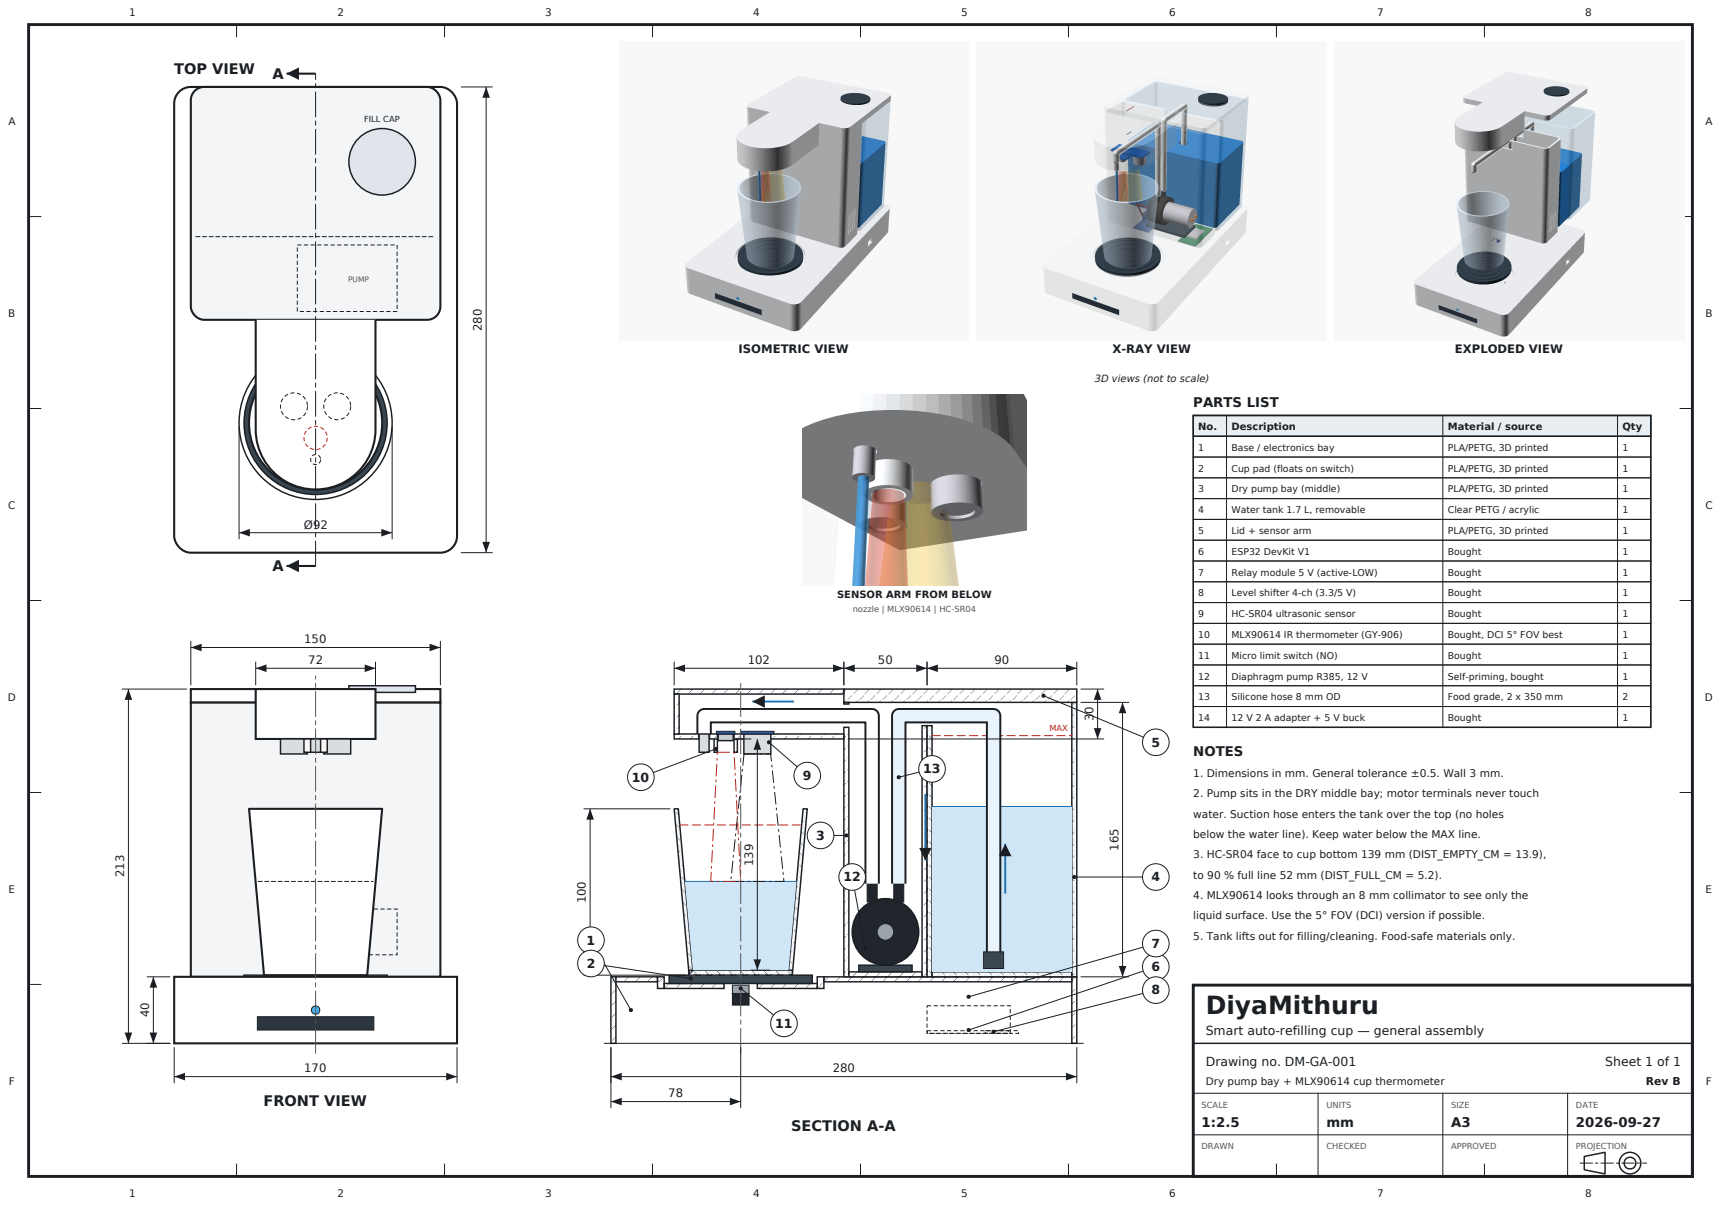
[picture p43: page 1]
FRONT VIEW; MAX; SECTION A-A; FILL CAP; PUMP; ISOMETRIC VIEW; X-RAY VIEW; EXPLODED VIEW; PARTS LIST; Description; Material / source; Qty; Base / electronics bay; PLA/PETG, 3D printed; Cup pad (floats on switch); Dry pump bay (middle); Water tank 1.7 L, removable; Clear PETG / acrylic; Lid + sensor arm; ESP32 DevKit V1; Bought; Relay module 5 V (active-LOW); Level shifter 4-ch (3.3/5 V); HC-SR04 ultrasonic sensor; MLX90614 IR thermometer (GY-906); Bought, DCI 5° FOV best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

3D views (not to scale)

SENSOR ARM FROM BELOW
nozzle | MLX90614 | HC-SR04

NOTES
1. Dimensions in mm. General tolerance ±0.5. Wall 3 mm.
2. Pump sits in the DRY middle bay; motor terminals never touch
water. Suction hose enters the tank over the top (no holes
below the water line). Keep water below the MAX line.
3. HC-SR04 face to cup bottom 139 mm (DIST_EMPTY_CM = 13.9),
to 90 % full line 52 mm (DIST_FULL_CM = 5.2).

4. MLX90614 looks through an 8 mm collimator to see only the
liquid surface. Use the 5° FOV (DCI) version if possible.
5. Tank lifts out for filling/cleaning. Food-safe materials only.
DiyaMithuru

Smart auto-refilling cup — general assembly

Drawing no. DM-GA-001
Dry pump bay + MLX90614 cup thermometer

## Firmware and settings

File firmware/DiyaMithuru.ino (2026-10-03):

/*
 * ============================================================
 *  DiyaMithuru - Smart auto-refilling cup  (ESP32, single file)
 * ============================================================
 *  Hardware (your wiring):
 *    Ultrasonic ECHO  -> level shifter HV1/LV1 -> GPIO 18
 *    Ultrasonic TRIG  <- level shifter LV2/HV2 <- GPIO 19
 *    Relay IN         -> GPIO 23   (active-LOW relay module)
 *    Limit switch NO  -> GPIO 27, COM -> GND
 *    MLX90614 SDA     -> GPIO 21   (I2C Data, 3.3V)
 *    MLX90614 SCL     -> GPIO 22   (I2C Clock, 3.3V)
 *
 *  How it works:
 *    - Cup placed  -> pump ON, fills until the cup is FULL
 *    - Cup removed -> pump OFF instantly
 *    - Level drops to LOW while the cup stays -> refills to FULL
 *    - Cup FULL    -> pump OFF, 2 seconds later detects drink temperature (MLX90614)
 *    - Web app (HiveMQ Cloud MQTT):  ON / STOP / FILL buttons,
 *      live level, drink temperature, and spoken announcements on the phone
 *
 *  Arduino libraries:  PubSubClient (by Nick O'Leary)
 *                       WiFiManager  (by tzapu / tablatronix)
 *                       Adafruit MLX90614 (by Adafruit)
 *  Board:              ESP32 Dev Module
 *
 *  MQTT topics:
 *    diyamithuru/cup01/cmd     <- "ON" | "STOP" | "FILL" | "PING" | "TEMP"
 *    diyamithuru/cup01/status  -> JSON (retained)
 *    diyamithuru/cup01/online  -> "1" / "0" (retained, last will)
 * ============================================================
 */

#include <WiFi.h>
#include <WiFiClientSecure.h>
#include <PubSubClient.h>
#include <WiFiManager.h>        // https://github.com/tzapu/WiFiManager
#include <Wire.h>
#include <Adafruit_MLX90614.h>

// ======================= SETTINGS ===========================
// WiFi is configured via the captive portal (WiFiManager).
// On first boot the ESP32 creates a hotspot called "DiyaMithuru-Setup".
// Connect to it from your phone → pick your network → enter password.
// Credentials are saved to flash and reused on every reboot.

// ---- HiveMQ Cloud ----
const char* MQTT_HOST = "b5ad82f71b0d40d6bcf02b00ce1cd933.s1.eu.hivemq.cloud";
const int   MQTT_PORT = 8883;
const char* MQTT_USER = "Diyamithuru";
const char* MQTT_PASS = "diyamithuru";
const char* DEVICE_ID = "cup01";          // must match the web app

// ---- Pins (from your circuit) ----
const int ECHO_PIN         = 18;
const int TRIG_PIN         = 19;
const int RELAY_PIN        = 23;
const int LIMIT_SWITCH_PIN = 27;

// ---- I2C Pins for MLX90614 Temperature Sensor ----
#define I2C_SDA 21
#define I2C_SCL 22

// Relay module logic (Active-LOW: LOW = ON, HIGH = OFF)
const int RELAY_ON  = LOW;
const int RELAY_OFF = HIGH;

// ---- Level calibration (cm from the sensor face) ----
const float DIST_EMPTY_CM = 12.0;   // sensor -> bottom of EMPTY cup  (0 %)
const float DIST_FULL_CM  = 4.0;    // sensor -> FULL water line      (100 %)

// ---- Fill behaviour ----
const int  LOW_THRESHOLD_PCT  = 30;     // refill when level drops to this
const int  FULL_THRESHOLD_PCT = 90;     // stop pump at this level
const bool FILL_ON_PLACE      = true;   // fill to FULL as soon as a cup is placed
const unsigned long CUP_SETTLE_MS        = 800;    // debounce before pumping
const unsigned long MAX_PUMP_RUN_MS      = 20000;  // safety stop (empty tank / leak)
const unsigned long DISTANCE_INTERVAL_MS = 250;    // level reading rate
const unsigned long TEMP_MEASURE_DELAY_MS = 2000;  // detect temperature 2s after cup is full
const unsigned long STATUS_MIN_GAP_MS    = 400;
const unsigned long STATUS_HEARTBEAT_MS  = 5000;
const unsigned long WIFI_PORTAL_TIMEOUT  = 180;    // portal auto-closes after 3 min
const unsigned long RESET_HOLD_MS        = 5000;   // hold limit switch 5 s at boot to reset WiFi
// ============================================================

String TOPIC_CMD, TOPIC_STATUS, TOPIC_ONLINE;

WiFiManager wm;                  // WiFiManager instance
WiFiClientSecure netClient;
PubSubClient mqtt(netClient);
Adafruit_MLX90614 mlx = Adafruit_MLX90614();

enum Mode { MODE_AUTO, MODE_PAUSED };
Mode mode = MODE_AUTO;

bool  cupPresent    = false;
bool  rawSwitchLast = false;
unsigned long switchChangedAt = 0;
unsigned long cupPlacedAt     = 0;

float distanceCm  = -1;
int   levelPct    = 0;
bool  levelValid  = false;
int   badReadings = 0;

bool  pumpOn     = false;
bool  fillToFull = false;   // set by cup placement or the FILL command
unsigned long pumpStartedAt = 0;
String fault = "";          // "", "TIMEOUT", "SENSOR"

// ---- Temperature state ----
bool  mlxAvailable       = false;
float cupTemp            = 0.0;
float ambientTemp        = 0.0;
bool  cupIsFull          = false;
bool  cupTempRead        = false;
unsigned long cupFullSince = 0;

unsigned long lastDistanceReadTime = 0;
unsigned long lastStatusAt  = 0;
unsigned long lastMqttTryAt = 0;
String lastStatusKey = "";

// ------------------------------------------------------------
//  Pump
// ------------------------------------------------------------
void setPump(bool on, const __FlashStringHelper* reason) {
  if (on == pumpOn) return;
  pumpOn = on;
  if (on) pumpStartedAt = millis();
  digitalWrite(RELAY_PIN, on ? RELAY_ON : RELAY_OFF);
  Serial.print(on ? F(">>> Pump ON  - ") : F("<<< Pump OFF - "));
  Serial.println(reason);
}

// ------------------------------------------------------------
//  Sensors
// ------------------------------------------------------------
float readDistanceCM() {
  digitalWrite(TRIG_PIN, LOW);
  delayMicroseconds(2);
  digitalWrite(TRIG_PIN, HIGH);
  delayMicroseconds(10);
  digitalWrite(TRIG_PIN, LOW);
  long duration = pulseIn(ECHO_PIN, HIGH, 25000);   // ~4.2 m max
  if (duration == 0) return -1.0;
  return (duration * 0.0343) / 2.0;
}

// Median of 3 quick readings removes splash spikes
float readDistanceMedian() {
  float a = readDistanceCM(); delay(8);
  float b = readDistanceCM(); delay(8);
  float c = readDistanceCM();
  if (a < 0 || b < 0 || c < 0) {                   // use what we have
    float best = max(a, max(b, c));
    return best;
  }
  return max(min(a, b), min(max(a, b), c));
}

void updateCupSwitch() {
  bool raw = (digitalRead(LIMIT_SWITCH_PIN) == LOW);  // pressed = cup on it
  unsigned long now = millis();
  if (raw != rawSwitchLast) { rawSwitchLast = raw; switchChangedAt = now; }
  if (now - switchChangedAt > 50 && raw != cupPresent) {
    cupPresent = raw;
    if (cupPresent) {
      cupPlacedAt = now;
      if (FILL_ON_PLACE) fillToFull = true;
      Serial.println(F(">>> Cup detected"));
    } else {
      fillToFull = false;
      setPump(false, F("cup removed"));
      cupIsFull = false;
      cupFullSince = 0;
      cupTempRead = false;
      cupTemp = 0.0;
      Serial.println(F("<<< Cup removed"));
    }
  }
}

void updateLevel() {
  unsigned long now = millis();
  if (now - lastDistanceReadTime < DISTANCE_INTERVAL_MS) return;
  lastDistanceReadTime = now;

  float d = readDistanceMedian();
  if (d < 0 || d > DIST_EMPTY_CM + 10) {
    if (++badReadings >= 4) levelValid = false;
    return;
  }
  badReadings = 0;
  levelValid = true;
  distanceCm = d;
  float pct = (DIST_EMPTY_CM - d) / (DIST_EMPTY_CM - DIST_FULL_CM) * 100.0;
  levelPct = constrain((int)(pct + 0.5), 0, 100);
}

// ------------------------------------------------------------
//  Fill logic
// ------------------------------------------------------------
void controlPump() {
  unsigned long now = millis();

  if (mode == MODE_PAUSED) { fillToFull = false; setPump(false, F("stopped by app")); return; }
  if (!cupPresent)         { setPump(false, F("no cup")); return; }
  if (now - cupPlacedAt < CUP_SETTLE_MS) return;       // wait for the cup to settle

  if (!levelValid) {
    if (fault != "SENSOR") Serial.println(F("[WARN] Level sensor not reading"));
    fault = "SENSOR";
    setPump(false, F("sensor not reading"));
    return;
  }
  if (fault == "SENSOR") fault = "";

  if (levelPct >= FULL_THRESHOLD_PCT) {
    fillToFull = false;
    setPump(false, F("cup full"));
  } else if (fillToFull || levelPct <= LOW_THRESHOLD_PCT) {
    fillToFull = true;                                  // once started, fill to FULL
    setPump(true, F("filling"));
  }

  // Safety: pump running too long means no water is arriving
  if (pumpOn && now - pumpStartedAt > MAX_PUMP_RUN_MS) {
    fillToFull = false;
    mode = MODE_PAUSED;
    fault = "TIMEOUT";
    setPump(false, F("SAFETY TIMEOUT - check tank/tube, send ON to resume"));
  }
}

// ------------------------------------------------------------
//  Temperature (MLX90614)
// ------------------------------------------------------------
void readCupTemperature() {
  if (!mlxAvailable) {
    Wire.begin(I2C_SDA, I2C_SCL);
    if (mlx.begin()) {
      mlxAvailable = true;
      Serial.println(F("[MLX] MLX90614 initialized successfully."));
    } else {
      Serial.println(F("[MLX] Error: MLX90614 not responding. Check wiring (SDA=21, SCL=22)."));
      return;
    }
  }

  float obj = mlx.readObjectTempC();
  float amb = mlx.readAmbientTempC();

  // Validate reading (-40 to 125 C is normal operational range)
  if (isnan(obj) || obj < -40.0 || obj > 150.0) {
    Serial.printf("[MLX] Invalid reading (obj=%.1f, amb=%.1f)\n", obj, amb);
    return;
  }

  cupTemp = obj;
  ambientTemp = amb;
  cupTempRead = true;
  Serial.printf("[TEMP] Detected 2s after full -> Object: %.2f °C | Ambient: %.2f °C\n", cupTemp, ambientTemp);
  publishStatus(true);
}

void updateTemperature() {
  unsigned long now = millis();

  // Reset temperature reading if cup is removed or pump is running
  if (!cupPresent || pumpOn) {
    if (cupIsFull || cupTempRead || cupTemp > 0.0) {
      cupIsFull = false;
      cupFullSince = 0;
      cupTempRead = false;
      cupTemp = 0.0;
    }
    return;
  }

  // Detect when cup is full (level >= 90% and pump is off)
  if (levelValid && levelPct >= FULL_THRESHOLD_PCT && !cupIsFull) {
    cupIsFull = true;
    cupFullSince = now;
    cupTempRead = false;
    Serial.println(F("[TEMP] Cup is full. Temperature will be detected in 2 seconds..."));
  }

  // If level drops back down while cup stays (e.g. user drinks), reset full state
  if (levelValid && levelPct <= LOW_THRESHOLD_PCT) {
    cupIsFull = false;
    cupFullSince = 0;
    cupTempRead = false;
    cupTemp = 0.0;
  }

  // 2 seconds after cup is full: detect temperature
  if (cupIsFull && !cupTempRead && cupFullSince > 0 && (now - cupFullSince >= TEMP_MEASURE_DELAY_MS)) {
    readCupTemperature();
  }
}

// ------------------------------------------------------------
//  MQTT
// ------------------------------------------------------------
void publishStatus(bool force) {
  // Build JSON with WiFi info so the web app can display it
  String ssid = WiFi.SSID();
  String ip   = WiFi.localIP().toString();
  int ch      = WiFi.channel();

  char buf[380];
  snprintf(buf, sizeof(buf),
    "{\"cup\":%s,\"level\":%d,\"distance\":%.1f,\"levelValid\":%s,"
    "\"pump\":%s,\"mode\":\"%s\",\"fill\":%s,\"fault\":\"%s\",\"rssi\":%d,"
    "\"temp\":%.1f,"
    "\"wifi_ssid\":\"%s\",\"wifi_ip\":\"%s\",\"wifi_ch\":%d}",
    cupPresent ? "true" : "false", levelPct, distanceCm,
    levelValid ? "true" : "false", pumpOn ? "true" : "false",
    mode == MODE_AUTO ? "AUTO" : "PAUSED", fillToFull ? "true" : "false",
    fault.c_str(), (int)WiFi.RSSI(),
    cupTemp,
    ssid.c_str(), ip.c_str(), ch);

  // Only the important fields decide "changed" (distance jitter is ignored)
  char key[80];
  snprintf(key, sizeof(key), "%d,%d,%d,%d,%d,%d,%s,%.1f",
           cupPresent, levelPct, levelValid, pumpOn, (int)mode, fillToFull, fault.c_str(), cupTemp);

  unsigned long now = millis();
  bool changed   = lastStatusKey != key;
  bool heartbeat = now - lastStatusAt >= STATUS_HEARTBEAT_MS;
  bool rateOk    = now - lastStatusAt >= STATUS_MIN_GAP_MS;
  if (force || heartbeat || (changed && rateOk)) {
    if (mqtt.connected()) mqtt.publish(TOPIC_STATUS.c_str(), buf, true);
    lastStatusKey = key;
    lastStatusAt  = now;
  }
}

void handleCommand(String cmd) {
  cmd.trim();
  cmd.toUpperCase();
  Serial.print(F("[APP] ")); Serial.println(cmd);

  if (cmd == "STOP" || cmd == "OFF") {
    mode = MODE_PAUSED;
    fillToFull = false;
    setPump(false, F("stopped by app"));
  } else if (cmd == "ON" || cmd == "START" || cmd == "AUTO") {
    mode = MODE_AUTO;
    fault = "";
  } else if (cmd == "FILL") {
    mode = MODE_AUTO;
    fault = "";
    fillToFull = true;
  } else if (cmd == "TEMP" || cmd == "READ_TEMP") {
    Serial.println(F("[APP] Manual temperature read requested"));
    readCupTemperature();
    publishStatus(true);
  } else if (cmd == "WIFI_RESET") {
    Serial.println(F("[WIFI] Resetting saved credentials..."));
    wm.resetSettings();
    delay(500);
    ESP.restart();
  }
  controlPump();
  publishStatus(true);
}

void onMqttMessage(char* topic, byte* payload, unsigned int len) {
  String msg;
  for (unsigned int i = 0; i < len; i++) msg += (char)payload[i];
  if (TOPIC_CMD == topic) handleCommand(msg);
}

void connectMqtt() {
  if (mqtt.connected() || WiFi.status() != WL_CONNECTED) return;
  unsigned long now = millis();
  if (lastMqttTryAt != 0 && now - lastMqttTryAt < 5000) return;
  lastMqttTryAt = now;

  String clientId = String("diyamithuru-") + DEVICE_ID + "-" + String((uint32_t)ESP.getEfuseMac(), HEX);
  Serial.print(F("[MQTT] Connecting to HiveMQ... "));
  if (mqtt.connect(clientId.c_str(), MQTT_USER, MQTT_PASS, TOPIC_ONLINE.c_str(), 1, true, "0")) {
    Serial.println(F("connected"));
    mqtt.publish(TOPIC_ONLINE.c_str(), "1", true);
    mqtt.subscribe(TOPIC_CMD.c_str(), 1);
    publishStatus(true);
  } else {
    Serial.printf("failed, rc=%d (retry in 5 s)\n", mqtt.state());
  }
}

// ------------------------------------------------------------
//  WiFiManager setup (replaces hardcoded credentials)
// ------------------------------------------------------------
void connectWifi() {
  WiFi.mode(WIFI_STA);

  // WiFiManager configuration
  wm.setConfigPortalTimeout(WIFI_PORTAL_TIMEOUT);  // auto-close portal
  wm.setConnectTimeout(15);                         // per-network timeout
  wm.setAPCallback([](WiFiManager* mgr) {
    Serial.println(F("[WIFI] Portal active. Connect to 'DiyaMithuru-Setup' hotspot."));
    Serial.print(F("[WIFI] Portal IP: ")); Serial.println(WiFi.softAPIP());
  });
  wm.setSaveConfigCallback([]() {
    Serial.println(F("[WIFI] Credentials saved!"));
  });

  // Try to connect with saved credentials.
  // If none saved (or they fail), starts AP 'DiyaMithuru-Setup'.
  Serial.println(F("[WIFI] Attempting auto-connect..."));
  if (!wm.autoConnect("DiyaMithuru-Setup")) {
    Serial.println(F("[WIFI] Portal timed out. Restarting..."));
    delay(1000);
    ESP.restart();
  }

  Serial.print(F("[WIFI] Connected! IP: "));
  Serial.println(WiFi.localIP());
  Serial.print(F("[WIFI] SSID: ")); Serial.println(WiFi.SSID());
  Serial.print(F("[WIFI] Channel: ")); Serial.println(WiFi.channel());
}

// Check if limit switch is held at boot → reset saved WiFi
void checkWifiReset() {
  if (digitalRead(LIMIT_SWITCH_PIN) == LOW) {
    Serial.println(F("[WIFI] Limit switch held at boot. Hold 5s to reset WiFi..."));
    unsigned long start = millis();
    while (digitalRead(LIMIT_SWITCH_PIN) == LOW && millis() - start < RESET_HOLD_MS) {
      delay(100);
    }
    if (millis() - start >= RESET_HOLD_MS) {
      Serial.println(F("[WIFI] WiFi credentials erased! Starting portal..."));
      wm.resetSettings();
      delay(500);
      ESP.restart();
    } else {
      Serial.println(F("[WIFI] Released early. Normal boot."));
    }
  }
}

// ------------------------------------------------------------
//  Setup / loop
// ------------------------------------------------------------
void setup() {
  Serial.begin(115200);

  // Safe relay setup: pump OFF at power-on
  pinMode(RELAY_PIN, OUTPUT);
  digitalWrite(RELAY_PIN, RELAY_OFF);

  pinMode(LIMIT_SWITCH_PIN, INPUT_PULLUP);
  pinMode(TRIG_PIN, OUTPUT);
  pinMode(ECHO_PIN, INPUT);

  String base  = String("diyamithuru/") + DEVICE_ID;
  TOPIC_CMD    = base + "/cmd";
  TOPIC_STATUS = base + "/status";
  TOPIC_ONLINE = base + "/online";

  Serial.println(F("\n=== DiyaMithuru ==="));

  // Check for WiFi reset (hold limit switch at boot for 5s)
  checkWifiReset();

  // Connect via WiFiManager (portal if needed)
  connectWifi();

  // HiveMQ Cloud needs TLS. setInsecure() encrypts but skips the
  // certificate check - fine for a prototype.
  netClient.setInsecure();
  mqtt.setServer(MQTT_HOST, MQTT_PORT);
  mqtt.setCallback(onMqttMessage);
  mqtt.setBufferSize(512);
  mqtt.setKeepAlive(30);

  // Initialize I2C with ESP32 default pins for MLX90614
  Wire.begin(I2C_SDA, I2C_SCL);
  Wire.setTimeOut(50);

  Serial.println(F("[MLX] Initializing MLX90614 on ESP32..."));
  if (mlx.begin()) {
    mlxAvailable = true;
    Serial.println(F("[MLX] Sensor connected successfully."));
  } else {
    mlxAvailable = false;
    Serial.println(F("[WARN] MLX90614 not found at boot. Check wiring (SDA=21, SCL=22)."));
  }

  Serial.println(F("[SYSTEM] Ready. Waiting for cup placement..."));
}

void loop() {
  if (Serial.available()) {
    String line = Serial.readStringUntil('\n');
    handleCommand(line);
  }

  connectMqtt();
  mqtt.loop();

  updateCupSwitch();
  updateLevel();
  controlPump();
  updateTemperature();
  publishStatus(false);
}
